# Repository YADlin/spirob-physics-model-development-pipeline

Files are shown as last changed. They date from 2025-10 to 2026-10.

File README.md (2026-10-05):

# SpiRob generator

Design a cable-driven SpiRob, inspect its geometry, and generate a **MuJoCo model** or **fabrication CAD** from one JSON file. Two cables use flat rectangular/hex links and hinge joints; three or more use notched n-lobe links and ball joints.

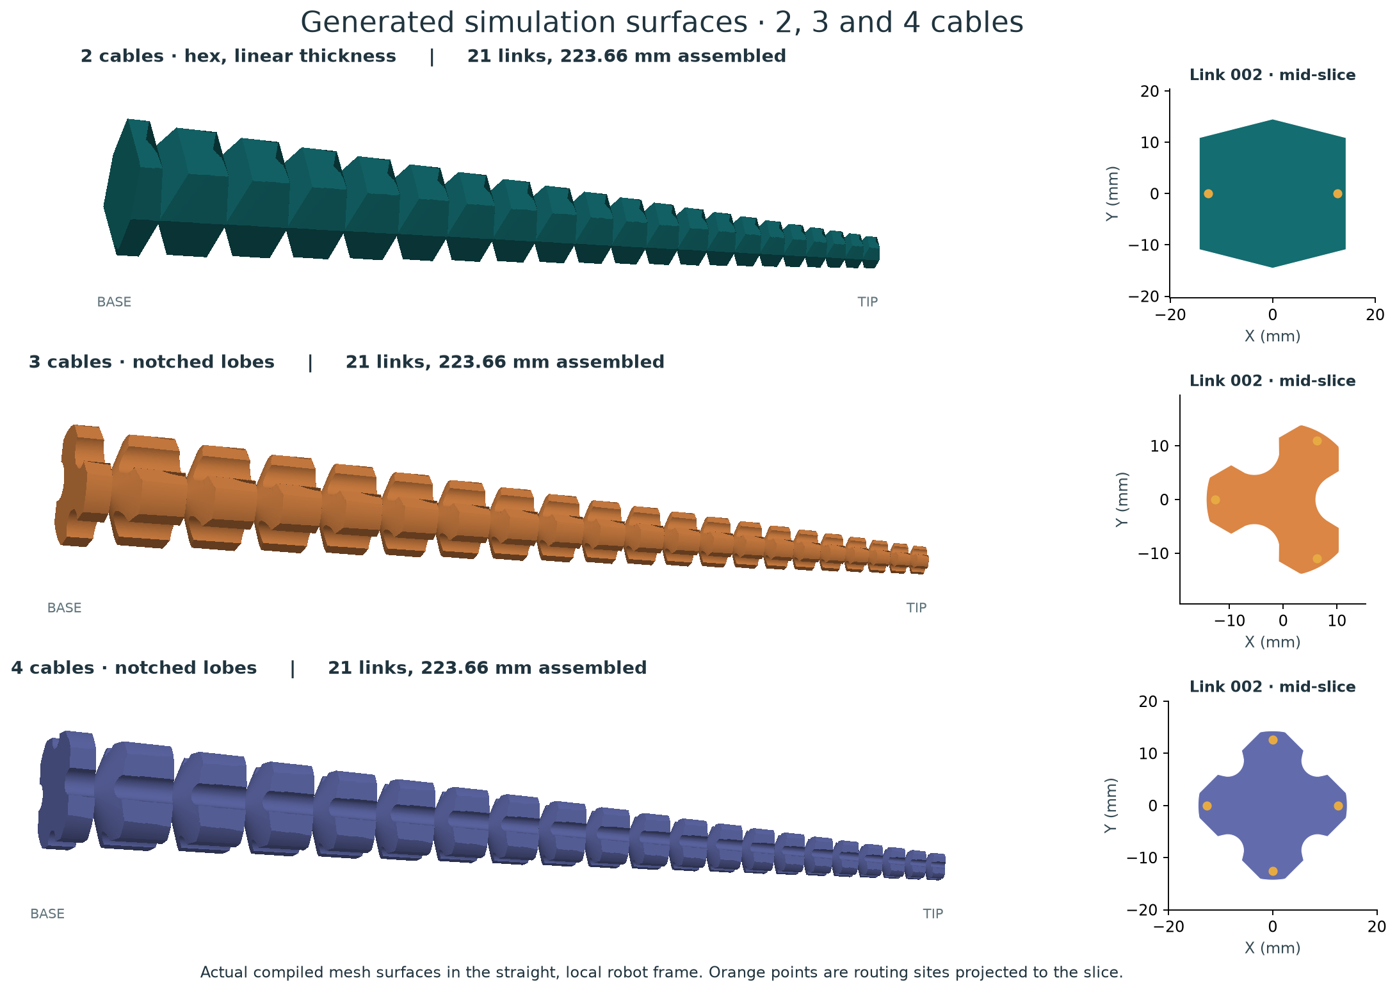
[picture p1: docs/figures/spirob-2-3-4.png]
Actual generated 2-, 3- and 4-cable SpiRob surfaces


**Start here:** [Install and build](#install-and-build) · [Interactive designer](#interactive-designer) · [Parameters](#parameters) · [Geometry equations](#geometry-equations) · [Dynamics and contact](#dynamics-and-contact) · [Tools](#tools) · [GitHub hosting](#github-hosting) · [Verification and layout](#verification-and-layout)

## Install and build

The supported environment is **Python 3.12**, managed by [uv](https://docs.astral.sh/uv/getting-started/installation/). Run commands from the repository root. `uv sync` creates `.venv`; activation is optional. Dependencies, including CAD and MuJoCo, are locked in `uv.lock`.

```bash
git clone git@github.com:YADlin/spirob-physics-model-development-pipeline.git
cd spirob-physics-model-development-pipeline
git switch fix/consolidation-cad-workflows
uv sync --locked
uv run python tools/designer.py
```

The review branch is shown above; after it is merged, use `main`. The designer opens at **http://127.0.0.1:8765**. Select a preset, adjust its parameters, then download JSON or generate a model ZIP. Stop the server with Ctrl+C after a build finishes.

For a terminal build and viewer:

```bash
uv run python build.py --params examples/params-three-cable.json --no-preview --output-dir build/three
uv run python -m mujoco.viewer --mjcf build/three/spirob_physics_model.xml
```

For two-cable hex links with an explicit **20 mm base thickness**, STEP, printing STL and IGES:

```bash
uv run python build.py --params examples/params-two-cable-hex.json --base-thickness-mm 20 --cad --iges --no-preview --output-dir build/two
```

Every build compiles its XML before publishing outputs. Failed stages preserve the previous output. Rebuilding without CAD removes stale CAD from that output directory. The obsolete red `target` site is **absent from new XML**; regenerate old models to remove it there too.

| Output under the chosen directory | Purpose / units |
| --- | --- |
| `spirob_physics_model.xml` + `meshes/` | Portable simulation model. Keep these together; simulation STL coordinates are **metres**. |
| `build_params.json` | Input with resolved build/CLI overrides. Omitted dynamics values still use the documented preset. |
| `Geom_Data_CSV/` | Intermediate geometry table; useful for auditing, not required by the viewer. |
| `collision_summary.json` | Contact geometry counts, mass isolation and arena allocation. |
| `section_dimensions.json` | Two-cable base/tip thickness and per-link taper dimensions. |
| `elastic_core_dimensions.json` | Core percentage, reference-width law and core dimensions at every joint and the tip. |
| `cad/spirob.step`, `cad/spirob.stl` | Whole-robot manufacturing exports in **millimetres**, when CAD is enabled. |
| `cad/spirob.iges` | Optional **trimmed BRep** interchange in mm; STEP is preferred for solids. |
| `cad/spirob_cad_report.json` | CAD validity, volumes, bounds, hashes and round-trip results. |
| `spirob_aligned.mjb` | Optional compiled frame-alignment experiment tied to MuJoCo 3.3.5. |

A fabrication STL and a simulation STL have different units and purposes. Do not send a metre-scale simulation mesh straight to a slicer expecting millimetres.

## Interactive designer

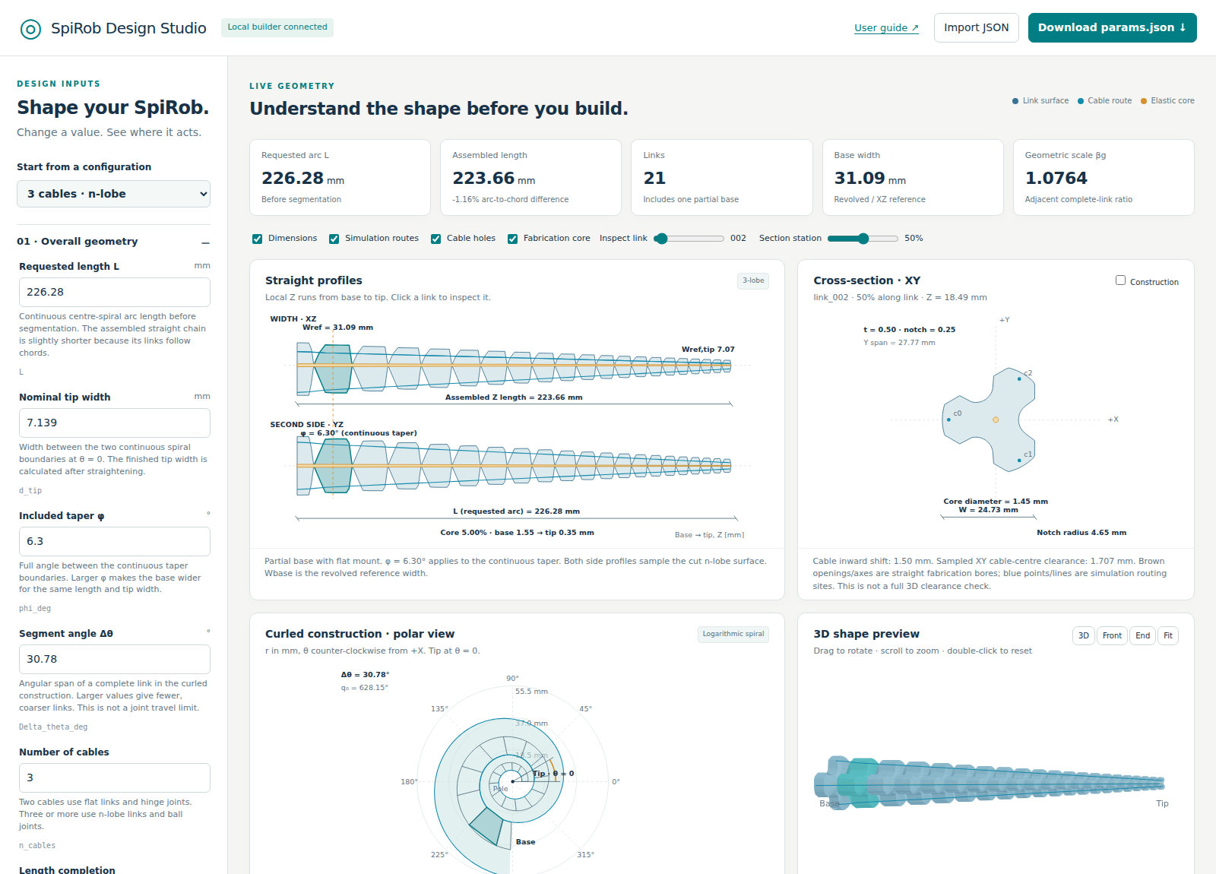
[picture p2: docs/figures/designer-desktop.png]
The SpiRob browser designer


The same interface runs locally or as a static GitHub Pages site. No JavaScript framework, CDN or web account is required to explore a design.

1. Choose a **2-hex, 2-rectangular, 3-, 4- or 6-cable preset**. Other cable counts can be entered.
2. Change length, tip width, taper and segment angle. The **front/side profiles** distinguish requested length from assembled length.
3. Click a link or use **Inspect link**. Move **Section station** to see a real XY slice, rather than a misleading full-link projection. Toggle **Construction** for the polygon and notch cutters.
4. Expand **Section** or **Fabrication** to change thickness, notch, fill, core and hole dimensions. The cross-section reports sampled XY wall clearance. Toggle dimensions, routes and core separately to control clutter.
5. Inspect the polar construction, back-calculated constants, gain plots and rotatable 3D surface. **Front**, **End** and **Fit** provide predictable camera views.
6. Download `params.json`. With the local builder connected, **Generate & download model** runs the Python pipeline and returns the XML, meshes, optional CAD and reports in one ZIP.

The browser remembers the last valid design locally. Importing a JSON file restores its settings; invalid values disable export/build and leave the previous valid preview visible with an error. Length inputs display **mm** while JSON uses metres. Optional omitted settings are identified in the controls.

The 3D view is a sampled design preview, not a contact simulation. Fabrication core/channel overlays explain parameters; the generated CAD is authoritative for the fused/drilled solid. Root world pose is applied in MuJoCo, not in the local design views. Interactive previews and browser builds are bounded to **32 cables / 400 links**; the terminal generator has no 32-cable limit.

**GitHub Pages is static hosting:** it serves the previews and JSON export but cannot execute this Python/OpenCascade pipeline. Exact exports work through the local builder or the manual GitHub Actions workflow described below. See [GitHub Pages documentation](https://docs.github.com/en/pages/getting-started-with-github-pages/what-is-github-pages).

## Parameters

Start with an example and edit it, or use the designer. The schema in [`site/parameters.schema.json`](site/parameters.schema.json) supplies field descriptions, units and basic validation to both Python and the website. Unknown keys, invalid types and non-finite numbers are rejected.

**Precedence:** explicit CLI option → JSON → generator/preset default. Schema `default` entries describe initial designer values; they do not silently insert missing keys into an imported file. The tables distinguish example values from omitted-key behavior where it matters.

### Geometry and sections

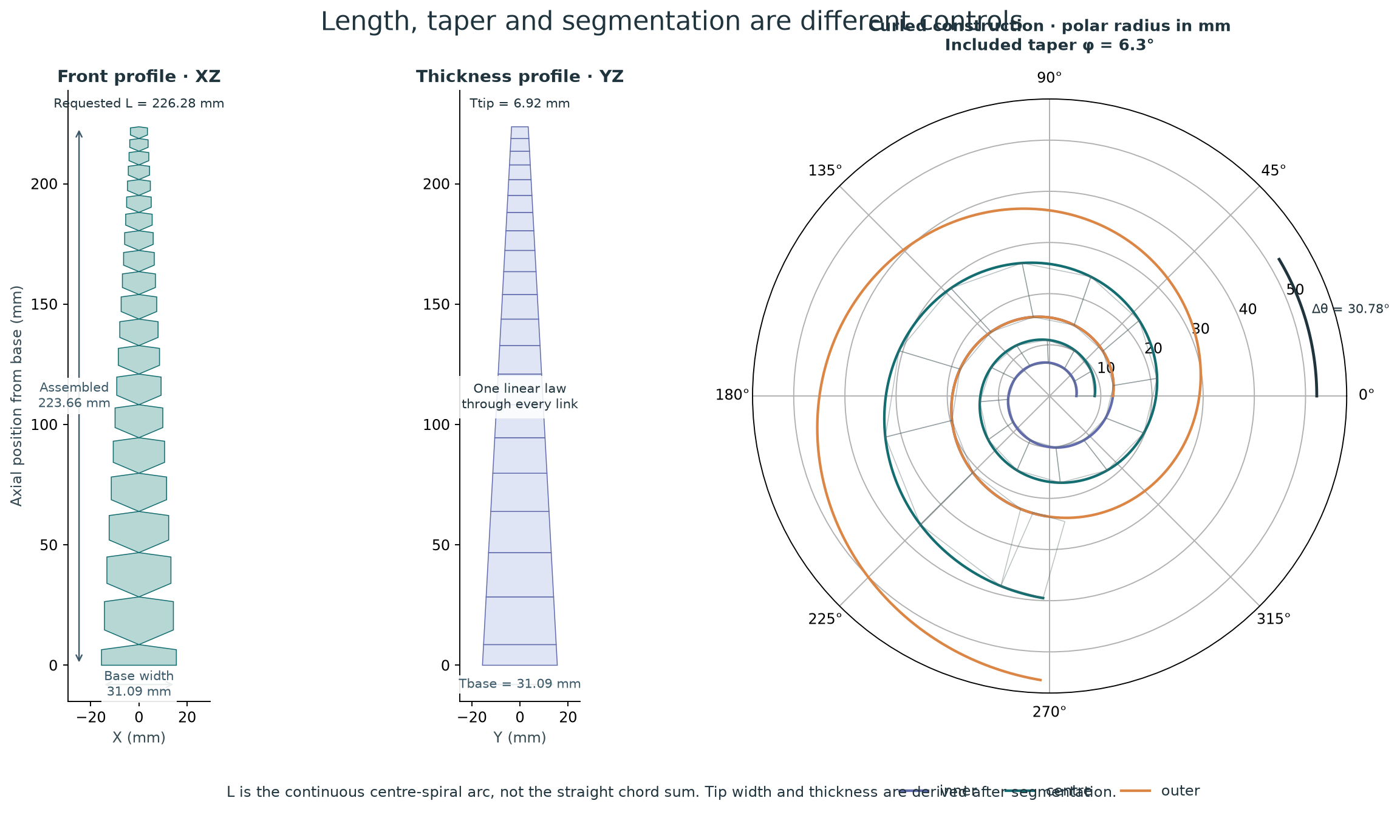
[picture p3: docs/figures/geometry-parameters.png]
Annotated geometry, thickness and spiral parameters


| JSON key | Example / default | Meaning and effect |
| --- | --- | --- |
| `L` | `0.22628` m; required | Continuous centre-spiral arc length before straightening. The assembled chain follows chords and is slightly shorter. |
| `d_tip` | `0.007139` m; required | Nominal width between spiral boundaries at θ=0. It is not necessarily the final measured tip width after segmentation. |
| `phi_deg` | `6.3`; required | Full included taper angle φ, **0 < φ < 45°**. Increasing it widens the base at a fixed length/tip input. |
| `Delta_theta_deg` | `30.78`; required | Curled angular span per complete link, **0 < Δθ < 180°**. Larger values mean fewer links; it is not a joint limit. |
| `n_cables` | `3`; required | Integer ≥2. Selects flat hinge links for 2, n-lobe ball-joint links for n≥3. |
| `terminal_unit_policy` | `exact_requested_length` | Preserve requested arc length and allow a partial base; `whole_units` extends the arc to the next complete link. An excessively short partial base is rejected; use whole units or adjust L/Δθ. |
| `tendon_inward_shift` | `0.0015` m; required | Inward routing-site offset; **0 ≤ shift < d_tip/2**. The distal site also receives a taper correction. This is not a guaranteed distance from a drilled hole to the actual outer surface. |
| `base_thickness_m` | `null` / auto | **2-cable only.** Full Y centre thickness at the base mounting plane. Auto equals base width; a number fixes that base thickness. Tip thickness is derived, not independently entered. |
| `thickness_profile` | `linear` | **2-cable only.** One continuous thickness law within and between links. `stepped` is the legacy constant-thickness-per-link alternative. |
| `flat_section` | `rectangular` | **2-cable only.** `hex` adds two centre ridges, giving a six-sided section; it is generally not a regular hexagon. |
| `hex_edge_ratio` | `0.75` | Hex only; **0 < ratio < 1**. Edge/centre thickness ratio at the link's full-width section. Sloped end-face clipping also changes a slice near a joint. |
| `nlobe_t` | `0.5` | **n≥3.** Polygon fill, **0–1**. Sets polygon circumradius relative to the revolved reference radius; changing it changes the lobe outline. |
| `notch_factor` | `0.25` | **n≥3.** Notch radius / half polygon-side length, **0–0.4**. Zero means no notch. Convex contact bridges these concavities. |
| `show_preview` | `false`; required | Open the optional desktop 2D approval window during a CLI build. `--no-preview` and the local browser builder suppress it. |

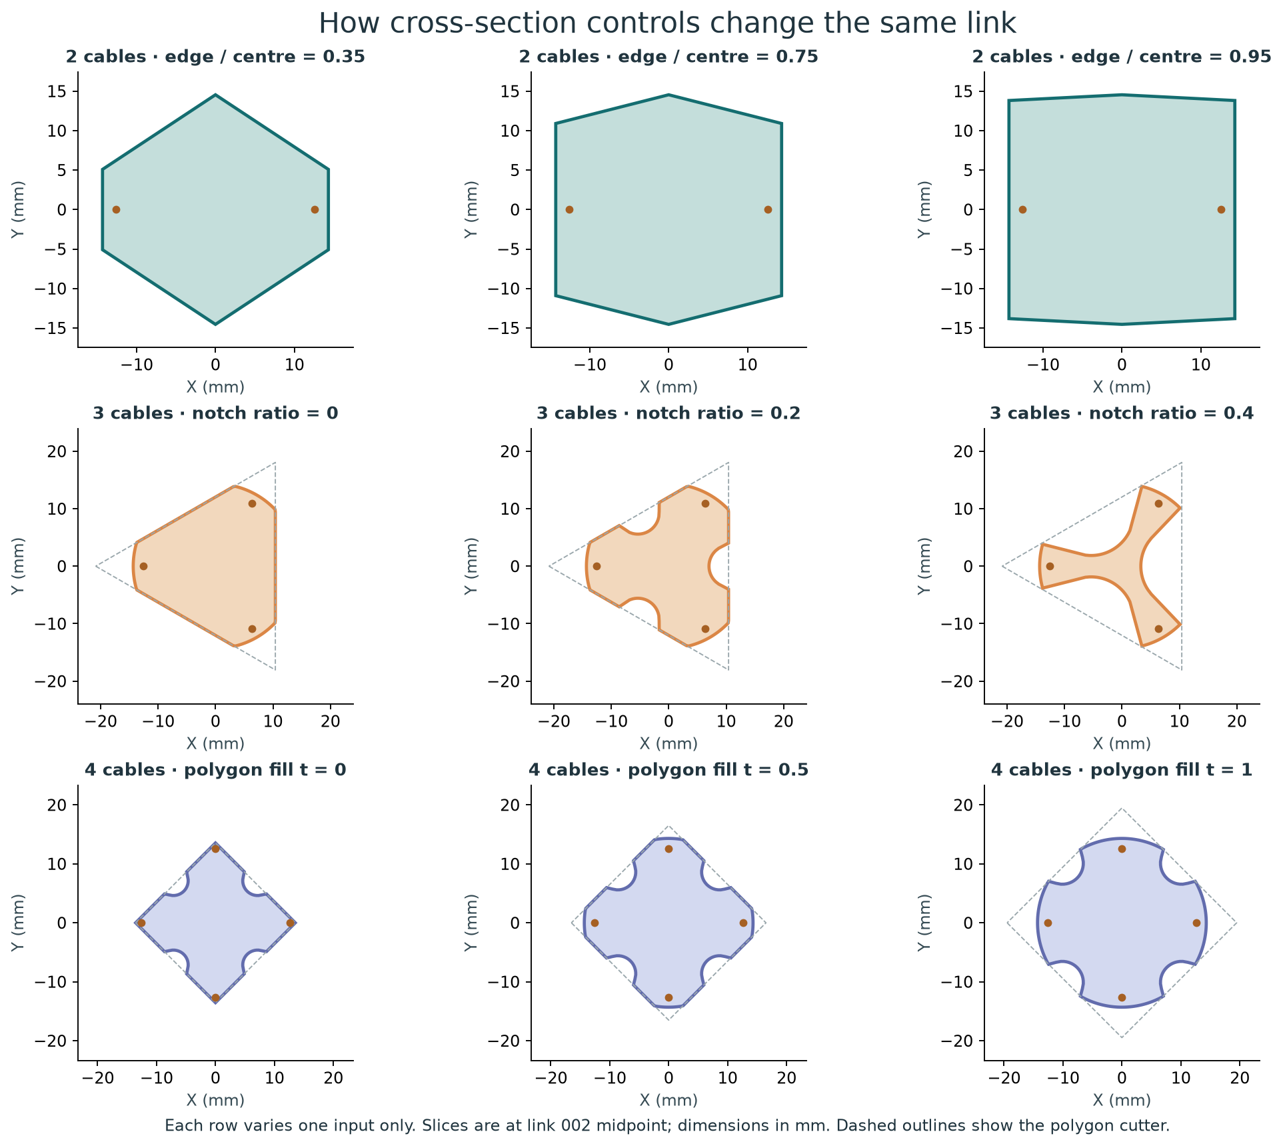
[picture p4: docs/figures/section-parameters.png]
Effects of hex edge ratio, notch ratio and polygon fill


For two cables the thickness law is

$$T(z)=T_\mathrm{base}\frac{z_\mathrm{apex}-z}{z_\mathrm{apex}-z_\mathrm{base}}.$$

The virtual apex continues the geometric sequence beyond the tip. This gives a linear taper and preserves similarity of complete links, so they can share an STL. The partial base gets its own STL. See `section_dimensions.json` for the resulting **base and tip** dimensions.

### Placement and dynamics: `post_gen`

These keys belong inside a `"post_gen": {...}` object. They are optional; examples explicitly set them for reproducibility.

| Key | Example | Meaning / omitted-key behavior |
| --- | --- | --- |
| `robot_pos` | `[0,0,0.22628]` m | Root body world position. If omitted, use the generated root position. |
| `robot_quat` | `[0,0,-1,0]` | Root orientation `[w,x,y,z]`, nonzero. The example points local +Z down. If omitted, use the generated orientation. |
| `joint_stiffness_base` | `0.2` N·m/rad | K₀ coefficient of the gain law below. Omitted uses the chosen preset. |
| `joint_damping_base` | `0.01` N·m·s/rad | D₀ coefficient; omitted uses the preset. |
| `joint_beta` | `1.03` | Positive gain-decay βⱼ, independent of geometric βg. Above 1 gives decreasing gains; 1 gives constant gains. |
| `first_joint_stiffness` | `100` N·m/rad | Override j_001 only. If omitted, j_001 follows K₀. A large spring approximates a fixed mounting; it is not a weld. |
| `first_joint_damping` | `50` N·m·s/rad | Override j_001 only. If omitted, it follows D₀. |
| `timestep` | `0.0001` s | Positive integration step. All supplied examples set this explicitly. Omitted uses the preset, which can be much coarser. |
| `tip_site_pos` | `[0,0,0.005]` m | Optional `tip_site` location in the **last body's local frame**; not a world position or guaranteed physical tip. Omitted means no tip site. |

`post_gen.target_site_pos` is retired: imports remove it with a notice and no target is emitted. The `--show-target-marker` flag has been removed.

### Export, collision and fabrication: `build`

These keys belong inside a `"build": {...}` object. The two example build entries are `collision_mode: "convex"` and `mesh_layout: "shared"`; other entries can be added in JSON or selected in the designer.

| Key | Default / example | Meaning |
| --- | --- | --- |
| `collision_mode` | Examples: `convex` | One massless convex hull per link. Alternatives: `mesh`, `capsule`, `compound`; comparison below. Omitted: mesh, or capsule with safe preset. |
| `mesh_layout` | `shared` | Reuse a complete-link STL plus a partial-base STL where needed. `individual` creates one mesh file per link. Names inside XML remain stable. |
| `physics_preset` | `default` | `default`, `safe`, `fast`, `high`. Selects the legacy dynamics/contact defaults; explicit overrides still win. |
| `collision_margin_m` | `null` / auto | Nonnegative activation margin in metres. Auto is **0 for convex/compound**, otherwise the preset value. |
| `collision_corner_radius_ratio` | `0.04` | Corner radius / half-width for legacy compound colliders only. Does not affect convex. |
| `arena_memory_mib` | `null` / auto | Positive integer native MuJoCo arena size. Auto is 128 MiB for compound, compiler default otherwise. More memory does not fix unstable dynamics. |
| `plain` | `false` | Advanced revolved circular-section comparison; bypasses flat/n-lobe cutters. Incompatible with convex/compound and explicit flat-section settings. |
| `align_geom_frames` | `false` | Additional version-specific aligned `.mjb`. Ordinary XML still uses MuJoCo's mesh principal frames. Usually leave off. |
| `cad` | `false` | Enable whole-robot STEP and mm STL export plus validation report. |
| `cad_profile` | `fabrication` | `fabrication` fuses a central elastic core and optional channels. `simulation` assembles the rigid link surfaces; it is not necessarily one printable part. |
| `elastic_core_percent` | `5` (%) | Core **X width for 2 cables**, **diameter for n≥3**, as a percentage of the local continuous reference width. Strictly between 0 and 100; `5` means 5%. Narrows continuously from base to tip. |
| `cable_hole_diameter_mm` | `0` mm | Fabrication channel diameter; 0 leaves CAD undrilled. Positive diameters require fabrication profile. Does not change tendon display width or simulation mass. |
| `fuse_cad` | `false` | Fuse simulation-profile solids where possible. Fabrication is already fused. Requires CAD. |
| `iges` | `false` | Also export trimmed IGES BRep, in mm. Requires CAD; STEP remains the preferred solid exchange format. |

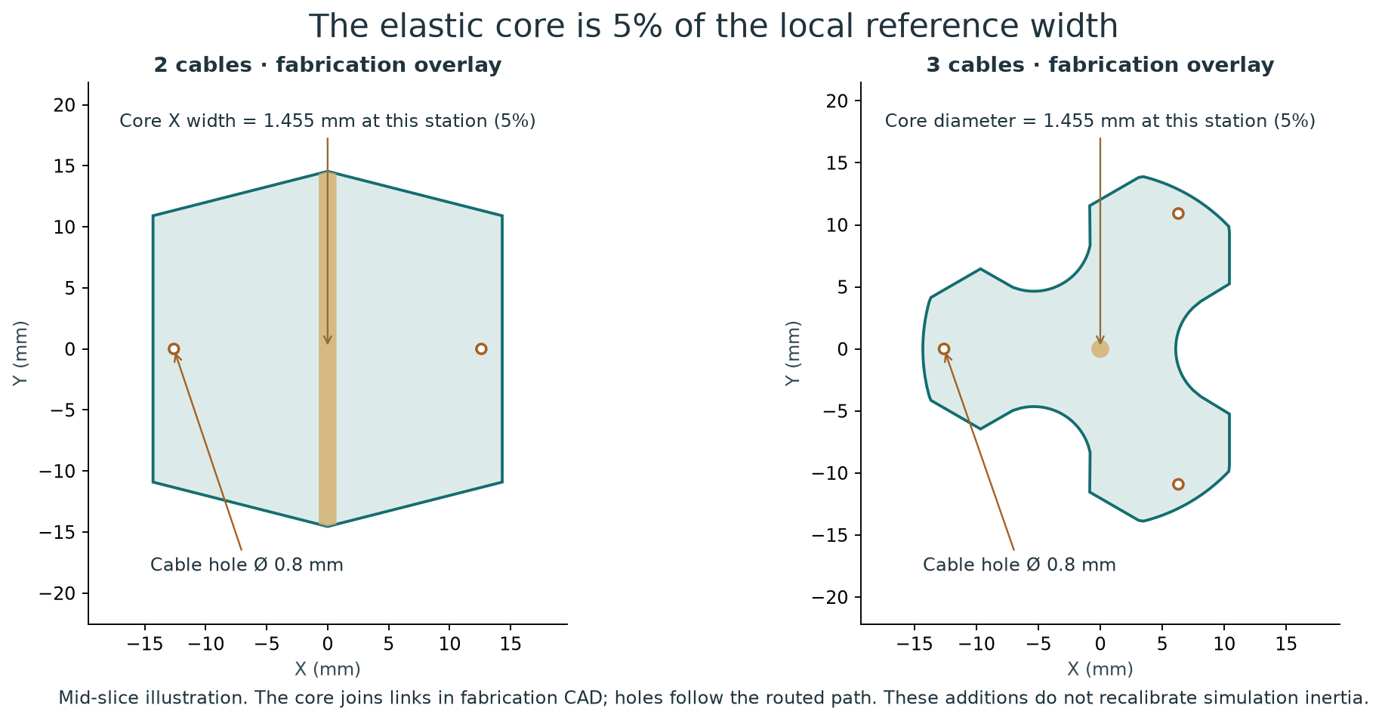
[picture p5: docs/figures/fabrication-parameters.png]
Core and cable-hole dimensions for two- and three-cable SpiRobs


**The elastic core must taper.** At axial position $z$, its X width (two cables) or diameter (n cables) is

$$c(z)=\frac{p}{100}W_{\mathrm{ref}}(z),\qquad
W_{\mathrm{ref}}(z)=W_{\mathrm{base}}\frac{z_* - z}{z_* - z_{\mathrm{base}}}.$$

Here $p$ is `elastic_core_percent`, and $z_*$ is the virtual apex beyond the tip. The reference width is the **continuous straightened, pre-notch envelope**, anchored to the base mounting width and the existing geometric similarity law. It is not the zero material width at a slit, the n-lobe notch clearance, or the XY bounding width of a clipped slice. All three fabrication formats use the same fused tapered solid.

For the supplied standard geometry at 5%, the reference width decreases from **31.087574 mm to 6.923663 mm**, and the core width/diameter decreases from **1.554379 mm to 0.346183 mm**. Two-cable core Y thickness follows the chosen link-thickness profile; with the default linear profile both transverse dimensions decrease. Its hex ridge edges follow the existing ridge geometry. For n cables the core is a circular conical frustum. An explicitly selected legacy stepped/lens Y profile retains that Y behavior; the new core X width still tapers continuously.

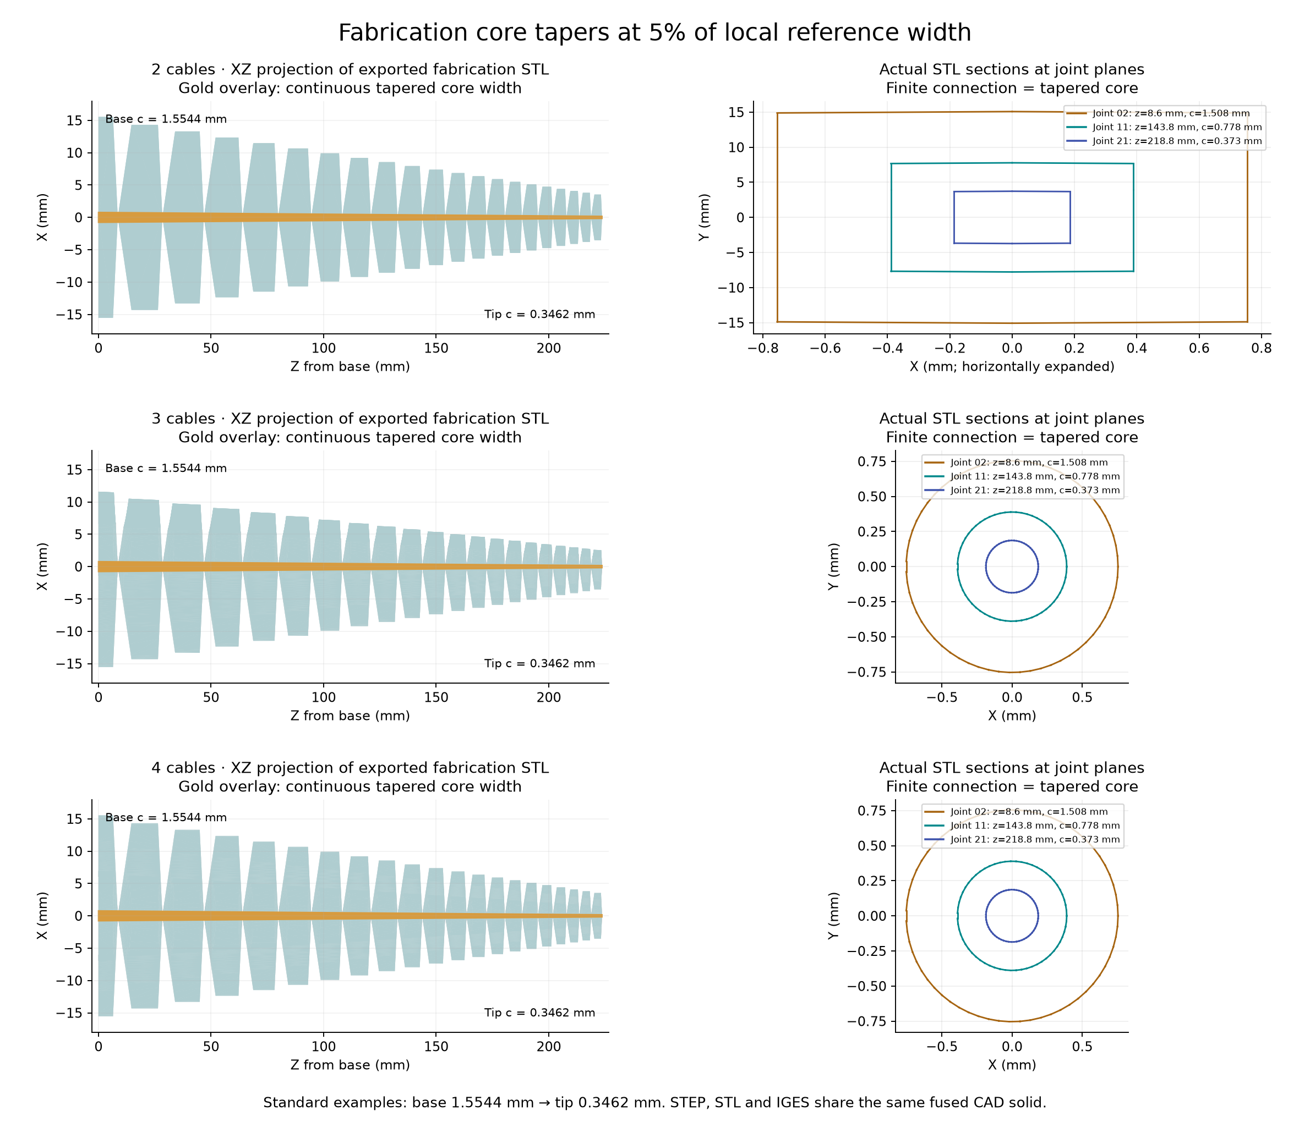
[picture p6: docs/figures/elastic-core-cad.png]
Tapered fabrication cores and their measured joint sections


```bash
uv run python build.py --params examples/params-two-cable-hex.json --elastic-core-percent 5 --cad --iges --no-preview --output-dir build/tapered-core-two
uv run python build.py --params examples/params-three-cable.json --elastic-core-percent 5 --cad --iges --no-preview --output-dir build/tapered-core-three
```

In JSON, set `"elastic_core_percent": 5` inside `build`. In the designer, expand **Elastic core & channels** and change **Elastic core / local width**. The core overlay, section dimensions and 3D core update together. Move the selected link and section station to see the narrowing. `elastic_core_dimensions.json` records joint-station values; the CAD report repeats the law used to construct the solid.

**Old inputs:** `build.neck_width_mm` and `--neck-width-mm` are migration inputs specifying the **base** core dimension. They now convert to a percentage, preserving that base size while reducing the tip. A notice identifies the behavior change. Do not supply both the legacy size and the percentage. There is no constant-width core mode in new fabrication exports.

**Original-author convention:** the inspected upstream DesignTool (`f563e69`) scales the half-taper angle by its “Elastic %”. Its corresponding width ratio is $\tan((p/100)\phi/2)/\tan(\phi/2)$, approximately $p/100$ for small angles. Our control explicitly specifies the width percentage requested here; the two numbers should not be treated as exactly identical. See [upstream DesignTool](https://github.com/ZhanchiWang/Open-Spiral-Robots/blob/f563e69f292a6b8cac1946dc45ad9e60d8795391/design-tool/DesignTool.py). The construction here is independent; no upstream implementation is copied.

The core controls geometry, not a separately identified material layer. Changing its percentage does **not** automatically calibrate joint gains or add the fabrication core/hole mass to the simulation inertias.

Cable-hole margin depends on the selected link, slice, notch shape, taper and hole diameter. The browser's XY clearance estimate is useful for locating thin walls, but is not a 3D minimum-wall or print-strength certification. Check the exported solid before printing.

### Compatibility inputs and command-line help

| Retained input | Purpose |
| --- | --- |
| `flat_thickness_ratio` | Old two-cable base thickness/width ratio, 0.05–1; mutually exclusive with `base_thickness_m`. Prefer absolute base thickness. |
| `flat_edge_ratio` | Old fabrication lens edge ratio, (0,1]; not the current hex-section control. |
| `taper_angle_deg` | Legacy alias; must agree with `phi_deg`. Use `phi_deg` in new files. |
| `build.flat_thickness_m`, `build.flat_edge_ratio` | Legacy stepped fabrication-lens overrides. Not supported with hex/linear thickness. |
| `_comment` | Optional explanatory string at root, in `post_gen`, or in `build`. |

Every terminal flag has help text:

```bash
uv run python build.py --help
uv run python tools/set_joint_gains.py --help
uv run python tools/add_touch_sensors.py --help
```

CLI names use hyphens: e.g. `--collision-mode convex`, `--arena-memory-mib 128`, `--elastic-core-percent 5`. `--base-thickness-mm 20` converts mm to the JSON metre value; `--base-thickness-mm auto` restores thickness=width. `--hex-section` selects hex, `--safe/--fast/--high` select a preset, and `--nlobe` restores the cable-count-driven section after `build.plain`. `--no-cad`, `--no-iges`, `--no-fuse-cad`, and `--no-align-geom-frames` can disable JSON options. `--noclean` is a retained no-op: builds always use fresh staging.

## Geometry equations

The original design principle is the logarithmic spiral **r(θ)=a exp(bθ)**, described by Wang, Freris and Wei in [SpiRobs: Logarithmic Spiral-shaped Robots for Versatile Grasping Across Scales](https://arxiv.org/abs/2303.09861). This generator solves for constants from more direct design inputs; the website displays their current values.

Let $E=e^{2\pi b}$. In this repository's convention:

$$r_\mathrm{in}(\theta)=ae^{b\theta},\quad r_\mathrm{out}(\theta)=ae^{b(\theta+2\pi)},\quad r_c(\theta)=\frac{a(E+1)}{2}e^{b\theta}.$$

$$\tan(\phi/2)=\frac{b(E-1)}{\sqrt{1+b^2}(E+1)},\qquad a=\frac{d_\mathrm{tip}}{E-1}.$$

$$A=\frac{\sqrt{1+b^2}\,a(E+1)}{2b},\qquad L=A(e^{bq_0}-1),\qquad q_0=\frac{\ln(1+L/A)}{b}.$$

Angles in these equations are **radians**. Complete units span Δθ and have geometric size ratio $\beta_g=e^{b\Delta\theta}$. The generator straightens each centre chord, reverses tip-to-base construction into base-to-tip numbering, and corrects a partial base's mounting face. Hence requested continuous length, discrete length and measured end widths differ. Whole-unit policy rounds the angular span upward before assembly.

For n-lobe links, the cutter has polygon circumradius $R_p=R[1+t(\sec(\pi/n)-1)]$ and notch radius $r_n=\text{notch\_factor}\,R_p\sin(\pi/n)$. The actual slice also includes axial draft and the revolved slit envelope; the website applies both.

## Dynamics and contact

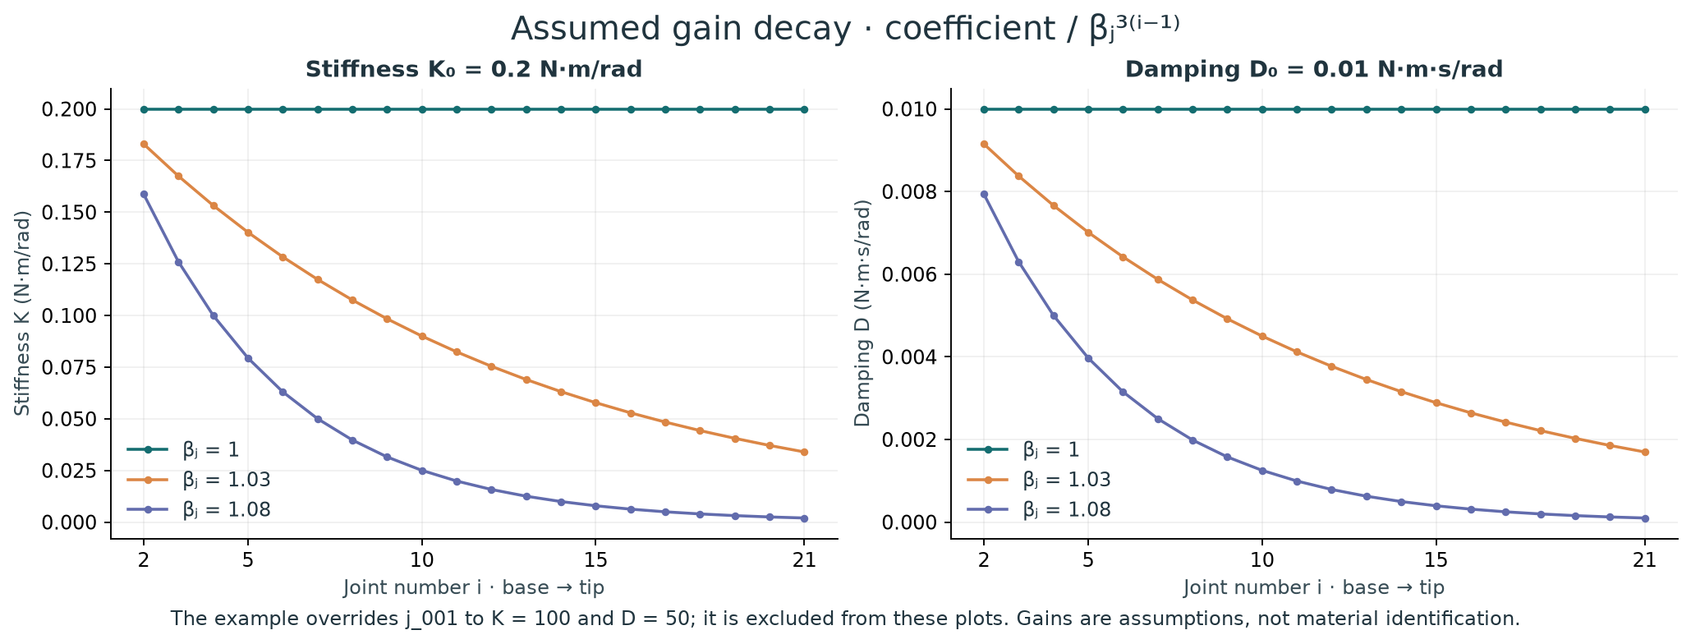
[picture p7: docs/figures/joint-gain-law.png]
Stiffness and damping curves for several decay assumptions


For base-to-tip joint number $i=1,\ldots,N$:

$$K_i=K_0/\beta_j^{3(i-1)},\qquad D_i=D_0/\beta_j^{3(i-1)}.$$

This is an **assumed exponential law in joint index** with the same exponent for damping and stiffness. It is retained and tested in this update. It is not fitted automatically to the printed material or inferred from CAD. βⱼ is independent of geometric βg. There is no linear joint-gain mode; the linear option described earlier refers to **link thickness**. The example's j_001 overrides are applied after this law. For ball joints, damping applies to their three rotational degrees of freedom.

### Why a linear core taper can coexist with exponential joint gains

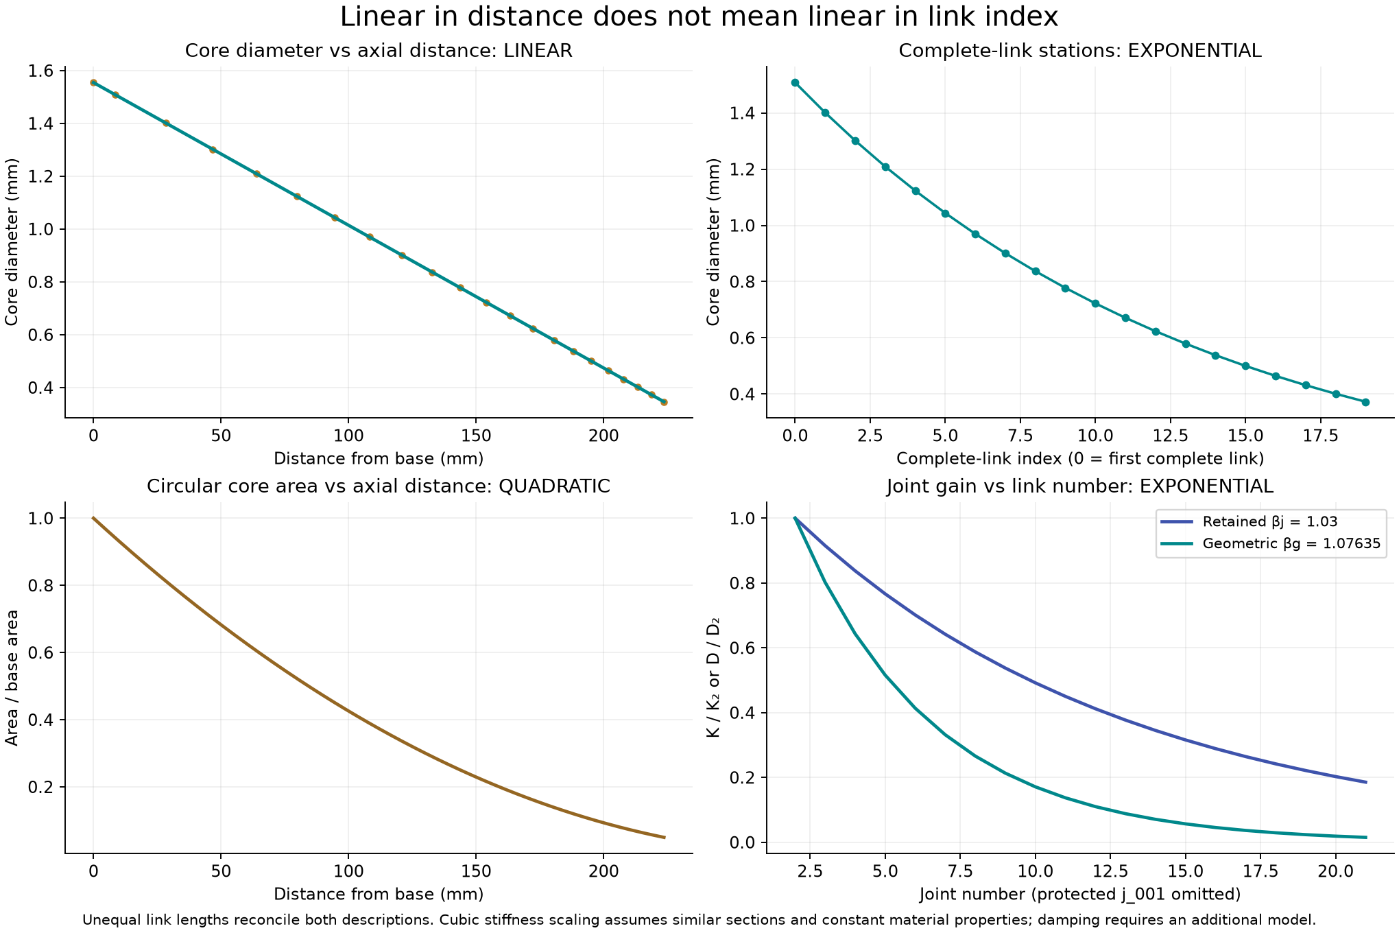
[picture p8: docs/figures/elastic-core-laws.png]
Width versus distance, width versus link index, and joint gain decay


Complete links occupy equal increments of spiral angle, **not equal axial distances**. Their sizes form a geometric sequence with tipward factor $s=1/\beta_g=e^{-b\Delta\theta}$. Sampling a linearly tapered width at these unequally spaced positions therefore gives an exponential sequence in link number. The partial base is handled by its actual length in the core geometry; it need not have the complete-link size ratio.

| Quantity / coordinate | Reduction toward the tip |
| --- | --- |
| Core width/diameter versus straight axial position $z$ | **Linear**, to a virtual apex beyond the actual tip. |
| Core width/diameter at corresponding complete-link stations | **Geometric / exponential**: one factor $1/\beta_g$ per link. |
| Nominal similar core cross-sectional area versus $z$ | **Quadratic** when both transverse dimensions scale; legacy fixed-Y variants differ. Hex CAD ridge clipping can introduce small departures from perfect section similarity. |
| Implemented stiffness and damping versus joint index | **Exponential**: one factor $1/\beta_j^3$ per joint, except explicit base overrides. |

For geometrically similar elastic sections of the same material, rotational bending stiffness scales approximately as $K\sim EI/\ell$. When all dimensions scale by $s$, $I\sim s^4$ and $\ell\sim s$, hence $K\sim s^3$. A linear Kelvin–Voigt bending model with a constant material viscosity gives the same cubic scale for damping; real TPU damping must be measured. This is the physical motivation for the exponent **3**, not proof that the current coefficients reproduce the printed robot.

`joint_beta` remains independent so existing calibrated/tuned configurations are preserved. To impose the complete-link similarity assumption, use the displayed **geometric βg** as `post_gen.joint_beta`. In the standard example βg ≈ **1.076353346**, while the retained example gain βj is **1.03**. They produce different gain reductions. With βj=βg, the ideal corresponding-station gain law is cubic in distance to the virtual apex; an arbitrary βj gives a different power of that distance. The current joint-index law is not corrected for a partial first link, and j_001 retains its independent mounting override. There is no claim of automatic physical calibration.

Legacy presets are retained, with their limitations visible:

| Preset | Timestep if omitted | Integrator | K₀ / D₀ if omitted | Motor control range | Margin for mesh/capsule |
| --- | --- | --- | --- | --- | --- |
| default | 0.002 s | implicit | 0.2 / 0.01 | −10 to 0 | 0.001 m |
| safe | 0.001 s | implicit | 0.2 / 0.2 | −5 to 5 | 0.0002 m |
| fast | 0.005 s | implicit | 0.01 / 0.001 | −10 to 10 | 0.002 m |
| high | 0.0005 s | RK4 | 0.1 / 0.02 | −5 to 5 | 0.0005 m |

**All current examples explicitly use 0.0001 s.** Their explicit K₀/D₀ also override preset gains. Preset names are not stability or physical-accuracy guarantees. Keep your known tolerable timestep and test the intended force/load range. With the default motor convention, negative control tensions the tendon; the symmetric legacy ranges also permit the opposite sign. Cable motors are idealized, not a hardware motor/cable model.

| Contact mode | Use / approximation |
| --- | --- |
| `convex` | Recommended starting point in examples: one massless contact hull per link, independent visual mesh and explicit inertia. Supports flat and n-lobe links. Bridges n-lobe concave notches. Multiple contact points can still be necessary for a broad face. |
| `mesh` | MuJoCo mesh contact uses a convex hull; it does not reproduce arbitrary concavity. Retains older contact settings. |
| `capsule` | Cheap rounded approximation, which can differ noticeably from flat faces. |
| `compound` | Legacy boxes/cylinders for **stepped rectangular two-cable links only**. More geom pairs and contacts; retained for comparisons. |

One hull per link reduces the number of contact geoms; it does **not** guarantee one contact or constraint per link. Dense folded configurations can still produce many contacts. Inspect force aggregation and solver statistics before increasing memory. Viewer `100% (76.2%)` describes requested versus achieved real-time speed; it is not an accuracy score.

Mass, COM and inertia are frozen into explicit `<inertial>` elements from the **simulation visual meshes** at generation time, using uniform density **1200 kg/m³**. Collision proxies have zero mass. Fabrication ligaments, holes, print infill and material variation are not automatically incorporated into this model. Geometry/density changes require regeneration; measured hardware properties require separate calibration. `audit_inertia.py` compares the assumptions transparently.

MuJoCo can rotate mesh geom frames to principal axes during compilation. This does not by itself rotate the physical surface incorrectly. Body/site naming is retained: `link_NNN`, `j_NNN`, `cC_NNN_s1/s2`, `cable_C`, `motor_cC`, and optional `tip_site`. See [MuJoCo's mesh documentation](https://mujoco.readthedocs.io/en/3.3.5/XMLreference.html#asset-mesh).

## Tools

All tools are included in the repository. Run them from the repository root. XML editing tools write a **separate compiled output** and rebase asset paths; keep the original meshes available. Use `--help` for complete options.

| Tool | When it helps |
| --- | --- |
| `tools/designer.py` | Interactive design and exact local model/CAD ZIP generation. `design_gui.py` is a compatibility launcher for this interface. |
| `tools/set_joint_gains.py` | Tune one stiffness/damping coefficient and decay factor across joints; always preserves j_001 and optional extra exclusions. |
| `tools/add_touch_sensors.py` | Add named spherical touch regions near cable routes while preserving existing sensors and physical properties. |
| `tools/audit_inertia.py` | Compare compiled mass/COM/inertia against the triangle mesh, independent simulation CAD, and optionally an older XML. |
| `tools/inspect_collision.py` | Show CAD and contact proxies, report counts/mass separation, or run a bounded actuator/contact stress test. |
| `tools/inspect_collision_surface.py` | Plot and quantify the visual-surface versus collision-hull difference, especially bridged n-lobe notches. |
| `tools/inspect_contact_forces.py` | Sum world-frame contact forces and moments on a body or within a chosen body-local spherical region. |
| `tools/inspect_section.py` | Plot actual compiled mesh projections and 3D views in body coordinates. Its end-on projection is not a planar slice. |
| `tools/inspect_taper.py` | Check two-cable thickness continuity against the requested law; optionally compare an older XML. |
| `tools/multi_array.py` | Assemble a circular array of robots with namespaced names and shared assets. |
| `fabrication/part_splitter.py` | Split STEP/STL to an axial printer span or explicit cuts; records part bounds and volumes. It does not add assembly keys or restore flexure continuity. |
| `tools/preview.py` | Optional desktop 2D geometry approval window used by `show_preview`. |
| `tools/inspect_model.py` | Advanced body/geom-frame inspection and optional compiled alignment. |
| `tools/geometry_audit.py` | Advanced requested/discrete length and geometry-policy report. |
| `tools/benchmark_collision.py` | Developer comparison of collider contact counts, timings and dense poses. Not a hardware validation. |

### Change gains and preserve the base

```bash
uv run python tools/set_joint_gains.py --mjcf build/three/spirob_physics_model.xml --out build/three/tuned.xml --stiffness 0.15 --damping 0.008 --beta 1.03 --json build/three/gain_changes.json
uv run python -m mujoco.viewer --mjcf build/three/tuned.xml
```

By default, the coefficient is anchored at the generator's i=1, while j_001 is preserved. Therefore j_002 gets coefficient/β³. Add `--anchor first-flexible` if the entered value should be the actual value at j_002. The tool verifies unchanged inertia, geometry, sites and actuator settings. For a permanent rebuild setting, also edit the corresponding `post_gen` values in your source JSON.

### Compare inertia in a useful frame

```bash
uv run python tools/audit_inertia.py --mjcf build/three/spirob_physics_model.xml --params build/three/build_params.json --links link_001 link_002 link_021 --json build/three/inertia.json
```

Reports express the tensor **at the compiled COM, with axes parallel to the link body frame**. CAD/mesh tensors are shifted to that same point before comparison, and each reference COM is reported separately. MuJoCo's diagonal principal moments alone would not permit a meaningful element-by-element comparison with a differently rotated CAD tensor. The reference is homogeneous CAD, not a measurement of a printed part. Adjust link names for a different link count.

### Inspect contact geometry and forces

```bash
uv run python tools/inspect_collision.py --mjcf build/three/spirob_physics_model.xml --view
uv run python tools/inspect_collision.py --mjcf build/three/spirob_physics_model.xml --stress --controls -2 0 0 --seconds 2 --ramp-seconds 1 --json build/three/contact_stress.json
uv run python tools/inspect_collision_surface.py --mjcf build/three/spirob_physics_model.xml --out build/three/contact_surfaces.png --json build/three/contact_surfaces.json
uv run python tools/inspect_contact_forces.py --mjcf build/three/spirob_physics_model.xml --body link_002 --seconds 2 --controls -2 0 0 --ramp-seconds 1 --json build/three/forces.json
```

For a region rather than the whole link, add `--point-local-m X Y Z --radius-m R`. A finite region aggregates nearby contacts; a mathematical point does not define a unique contact-force distribution. Reports state which body receives the force and the moment reference. No-contact states naturally return zero.

### Add touch readings

```bash
uv run python tools/add_touch_sensors.py --mjcf build/three/spirob_physics_model.xml --out build/three/touch.xml --links 2 3 --offset-mm 1.8 --radius-mm 3
```

This adds regions named `cs_NNN_cC` and sensors named `touch_NNN_cC`. MuJoCo touch readings sum **normal contact-force magnitudes** within a region; they are not independent 3D force vectors. Overlapping regions may count the same contact. Use the contact-force inspector for vector forces and moments. See [MuJoCo touch sensor semantics](https://mujoco.readthedocs.io/en/3.3.5/XMLreference.html#sensor-touch).

### Check thickness, make an array, or split a print

```bash
uv run python tools/inspect_taper.py --mjcf build/two/spirob_physics_model.xml --params build/two/build_params.json --out build/two/taper.png --json build/two/taper.json
uv run python tools/inspect_section.py --mjcf build/three/spirob_physics_model.xml --out build/three/sections.png
uv run python tools/multi_array.py --in build/three/spirob_physics_model.xml --count 4 --radius-m 0.12 --out build/array.xml
uv run python fabrication/part_splitter.py build/two/cad/spirob.step --axis z --max-span-mm 100 --file-units mm --out-dir build/two/print-parts
```

Fabrication exports use the robot's local +Z axis. Splitting reports geometric pieces, not a tested mechanical connection. Inspect where the core and cable channels intersect each cut.

## GitHub hosting

The site and workflows are included; publication is a separate repository action. You can review everything locally before merging.

**After the workflow files reach the default branch:**

1. In GitHub, open **Settings → Pages → Build and deployment → Source: GitHub Actions**.
2. Open **Actions → Deploy SpiRob designer → Run workflow**. Select the branch/ref you intend to publish.
3. Use the URL reported by the deployment. For this repository, the normal project URL is `https://yadlin.github.io/spirob-physics-model-development-pipeline/`; it becomes available only after a successful deployment.
4. To generate files on GitHub, open **Actions → Generate SpiRob model → Run workflow**. Choose a preset or paste a complete exported JSON. Enable `build.cad` and `build.iges` in that JSON for CAD/IGES. Download `spirob-model` from the completed run's artifacts (retained for 14 days).

The website never asks for a GitHub token. Manual Actions builds require repository write access; public visitors can use JSON export and the local builder. A manual workflow must exist on the default branch before GitHub exposes it, even if a later run selects another branch. See [manual workflow requirements](https://docs.github.com/en/actions/how-tos/manage-workflow-runs/manually-run-a-workflow) and [Pages custom workflows](https://docs.github.com/en/pages/getting-started-with-github-pages/using-custom-workflows-with-github-pages).

## Verification and layout

```bash
uv sync --locked
uv run pytest -q
```

For website development, Node 22+ is needed only for checks, not for serving the site:

```bash
uv run python dev/check_web_geometry.py
uv run python dev/check_web_sections.py
npm --prefix dev/browser ci
cd dev/browser
npx playwright install chromium
cd ../..
node dev/browser/check.mjs
uv run python dev/render_readme_figures.py
```

The browser check exercises real controls, JSON persistence, mobile layout and a downloadable XML/STL/STEP/IGES build. Geometry parity compares 24 browser/Python configurations. README figures are reproducible from generated meshes and the same section equations; they are not hand-drawn approximations of hardware.

**Known test status:** one strict expected failure records the retained distal-tendon taper correction (F08), which does not produce a constant surface offset. It is not an unexplained crash; changing it needs a separate routing/physics decision. Sixteen skips cover unsupported n-cable compound combinations; three skips exclude non-legacy profiles from a deliberately legacy benchmark. These do not skip convex coverage. Unexpected failures or new skips still need investigation. See the [current branch audit](docs/engineering/BRANCH_AUDIT.md) for measured results and remaining work.

| Location | Responsibility |
| --- | --- |
| `build.py`, `params.json`, `examples/` | User entry point and reproducible input configurations. |
| `spirob/geometry.py`, `sections.py`, `collision.py` | Canonical geometry, cross-sections and collision construction. |
| `spirob/pipeline/` | CSV, STL, MJCF and CAD stages; normally called through `build.py`. |
| `spirob/parameters.py`, `xml_tools.py`, `mesh_assets.py` | Validation, safe XML editing and shared mesh mapping. |
| `tools/`, `fabrication/` | User inspection/tuning tools and print splitting. |
| `site/` | Static designer, shared parameter schema and browser presets. |
| `tests/`, `dev/` | Regression tests, independent legacy reference and browser/figure checks. |
| `docs/figures/`, `docs/engineering/` | README illustrations and detailed engineering history. This README is the current user guide. |
| `build/` | Generated models, reports and downloads; ignored by Git. |
| `pyproject.toml`, `uv.lock` | Supported environment and reproducible dependencies. |

The former root-stage scripts moved to `spirob/pipeline/`; use `build.py` instead of invoking those stages by path. `design_gui.py` now opens the browser designer. The old touch script and XML updater are replaced by the tools above. Duplicate DOCX/HTML/manual versions and requirements lists were removed. Old engineering reports are explicitly marked historical. Existing ignored root outputs are not deleted automatically; the new default build location is `build/spirob`.

For contributor changes, create a branch, run relevant tests, review `git diff`, commit source changes explicitly, and submit a PR. Do not commit generated model folders or `.venv`. The locked environment is intended for this repository checkout; installing an arbitrary standalone wheel is not the documented workflow.

## Scope and attribution

This is an independent MIT implementation extending the geometry and naming conventions of this repository. The original design and research are credited to [Zhanchi Wang, Nikolaos M. Freris and Xi Wei](https://arxiv.org/abs/2303.09861); their [Open-Spiral-Robots repository](https://github.com/ZhanchiWang/Open-Spiral-Robots) remains a separate project with its own license. Its noncommercial source is not incorporated here. CADQuery/OpenCascade, MuJoCo and other dependencies retain their respective licenses.

Remaining physical work includes experimental stiffness/damping identification, printed-part inertia calibration, and contact validation in deep concavities. The current n-lobe CAD path retains individual solid construction: extending shared-solid reuse showed small numerical volume differences and is deferred until independently resolved.

## Downloadable design and build records

Every successful `build.py` run now saves `design_report/report.md`, its figures,
a self-contained `design_report/report.html`, and a portable `design_report.zip`
inside the output directory. This also applies to the local designer's model ZIP
and the **Generate SpiRob model** GitHub Actions artifact. No extra flag or Node
installation is needed for terminal report generation.

```bash
uv run python build.py --params params.json --no-preview --output-dir build/my-spirob
xdg-open build/my-spirob/design_report/report.html
```

The HTML copy includes **Print / Save as PDF**. Select **Save to PDF** in the
browser print dialog. For Markdown, keep `report.md` beside its `figures/` folder;
share `design_report.zip` to preserve those links.

On the website, click **Download design report** beside **Copy JSON**. This works
on GitHub Pages without a Python server. Extract the downloaded ZIP and open
`report.html` or `report.md`. It records the selected link/station and current
label, core overlay and camera settings; turn on the annotations you want before
exporting. It includes the exact current SVG views and a 3D snapshot.

The website-only download is labelled **design preview** because no model build
has run. The report in a generated model ZIP is a **completed build record**:
resolved JSON includes command-line overrides, while joint gains and timestep
are read from the compiled MJCF. Terminal figures show actual simulation meshes,
representative mid-sections, core reference dimensions, spiral and gains; they
are not screenshots of a user's browser camera or fabrication hole verification.
Both records include creation time, parameter SHA-256, spiral constants and
modelling assumptions. Completed reports also include source revision and
`output_checksums.json`, identifying the generated files. Subsequent manual XML
or CAD edits do not revise the original report.

After applying this update, deploy **Deploy SpiRob designer → Run workflow → main**
to publish the new report button. Updating the repository alone does not publish
the website.

## Two-cable constant thickness (parallel flat faces)

On the website choose **2 cables · rectangular**, then under **Cross-section**:
set **Axial thickness law → constant**, disable **Base centre thickness automatic**,
and enter the desired thickness in mm. For example, 3 mm gives a 3 mm Y thickness
at the base, every intermediate link, and the tip. The side profile, cross-section,
3D preview, JSON and downloadable report all reflect this selection.

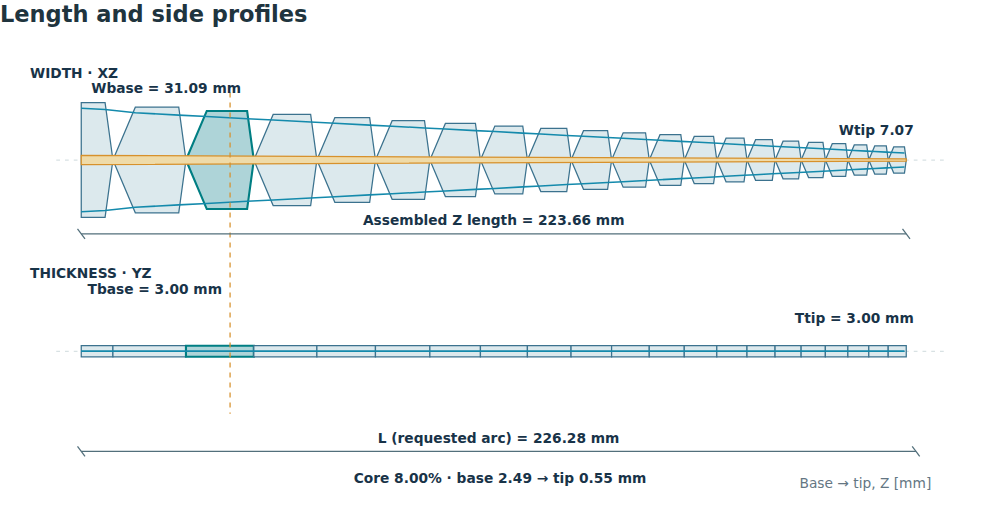
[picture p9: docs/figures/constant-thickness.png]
Constant 3 mm thickness: the YZ faces stay parallel while XZ width tapers


```bash
uv run python build.py --params examples/params-two-cable.json \
  --thickness-profile constant --base-thickness-mm 3 \
  --cad --iges --no-preview --output-dir build/flat-3mm
```

This applies to simulation meshes, collision hulls, and fabrication STEP/STL/IGES.
Shared meshes retain their full Y thickness and scale only in X and Z.
`constant` is different from `stepped`: stepped links become thinner toward the
tip. The XZ width taper, slits and percentage-based core X width still narrow
normally. Rectangular sections give parallel flat outer faces; a hex section
retains its transverse ridges, with constant centre and edge thickness along Z.
Automatic thickness uses the base width as the constant thickness.

Joint gains remain independently configured. Constant Y thickness breaks the
all-dimensions-similar assumption behind cubic stiffness scaling; calibrate the
gains for the manufactured design rather than treating the existing exponential
law as a consequence of this geometry. Deploy the updated website after merging.

## Cable bores and the partial base link

Fabrication holes now use **one straight cylindrical cut per cable**, connecting
that cable's first and last simulation routing anchors and extending to the base
and tip planes. The old round-transition sweep followed every simulation routing
segment and could introduce curved transition patches near the partial base.
The cutter now extends only a small diameter-dependent clearance beyond the ends.

The simulation's existing routing sites and dynamics are retained. They can
therefore differ from the straight manufacturing axis, especially at a partial
base. The CAD report records the maximum route deviation and both bore endpoints;
this difference matters when comparing hardware to an existing calibrated model.
Regenerate the CAD to apply the change; old downloads are unchanged.

With a positive **Cable hole diameter**, the website's **Cable holes** checkbox
shows bore openings in the cross-section and 3D preview and brown dashed straight
axes on the side profiles. Blue **Simulation routes** remain independently
switchable. Select **End** to see the openings. The 3D preview omits interior bore
wall shading; the STEP/STL/IGES files contain the full cylindrical walls.

Checks now include full-length bore-probe intersection on STEP, centre/ring ray
checks on STL, a single connected STL component and tighter tessellation around
small bores. IGES uses trimmed BRep export, with all six bounding coordinates and
face count checked after reimport. CAD topology checks do not certify print
settings, support generation or hole fit after printing.

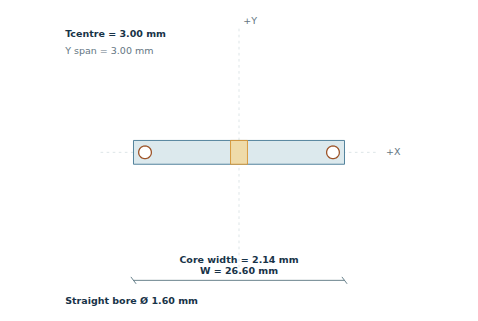
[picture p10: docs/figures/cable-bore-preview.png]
Website cross-section showing the straight fabrication bores


See [the bore update notes](docs/engineering/CABLE_BORE_UPDATE.md) for the route definition, export checks and findings from the supplied CAD files.

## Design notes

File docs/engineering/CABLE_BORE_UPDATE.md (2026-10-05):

# Straight fabrication bores and trimmed IGES export

The prior fabrication exporter swept a circle around every MJCF routing point
with round transitions. Exact-length designs include a partial base, and its
routing anchor does not lie on the continuation of the complete-link route.
Round transitions introduce small revolution surfaces near that kink. Cutter
extensions were one entire robot length, leaving remote analytic surface origins.

The manufacturing route now uses the first and last routing anchors to define a
single straight axis, extrapolated to the base and tip planes. Each bore is cut
with one cylinder, extending only a diameter-dependent clearance past the ends.
The MJCF route is not silently changed: changing it affects tendon lengths,
moment arms and calibration. CAD reports record the difference in millimetres.

Validation now checks a full-length 99.9%-diameter probe in STEP and IGES, and
33 centre/ring rays through each STL bore up to 95% of its diameter. STL tolerance
is capped at 0.5% of the bore diameter. Disconnected STL components are rejected.
IGES uses mode 1 (trimmed BRep) and validates face count, solid count and all six
bounding coordinates on reimport, not just the three bounding-box extents.

The website displays the same axes, true elliptical XY bore intersections, and
3D face openings. The sampled 3D display omits internal bore-wall shading and is
not a substitute for the checked fabrication exports. Brown marks are bores;
blue marks are the independent simulation routes. Hole visibility does not
depend on the simulation-route checkbox. End view is oriented consistently with
the XY cross-section; coincident base/tip labels are suppressed.

## Uploaded-file diagnosis

The inspected STEP was one valid solid; its STL was one closed connected volume.
The IGES contained 298 trimmed faces and no face outside the same model bounds.
There were no detached spherical solids. Six small revolution transition patches
occurred around Z = 9.99 and 18.27 mm. Two base-hole cylinder surface origins were
at Z = -227.109 mm, despite their trimmed faces being within the robot.
Displaying untrimmed support geometry can therefore explain the reported remote
cylinders, but this depends on the importing CAD application.

Sampled centre lines of the base-region cylindrical segments were open in the
supplied STEP. The physical print blockage is not conclusively diagnosed from
these files: it must not be reported as a proven pair of solid spheres. The
uploaded params.json and slicer project were not supplied. Regenerate from the
original JSON to reproduce the exact design with the new bore construction.

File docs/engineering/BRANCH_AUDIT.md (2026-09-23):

> Historical audit for 090665f. For the 23 September tapered-core correction, see ELASTIC_CORE_UPDATE.md and the current README.

# Branch audit and designer handoff

Review base: `ad64c019504bbfcd32a7e879e224cb3c8105b9d3` on `fix/consolidation-cad-workflows`.

This report records the current cleanup. The [README](../../README.md) is the user guide; other reports in this folder describe earlier work. The review is prepared for the branch, without merging `main` or publishing the site.

## Main and branch inventory

Remote refs checked on 19 September 2026: `main` is `55cc5f10594f9ada18d21b872e4d13fbc266e064`; the published working branch is `ad64c019504bbfcd32a7e879e224cb3c8105b9d3`. Main is an ancestor of the working branch (13 earlier feature/fix commits), with no main-only commits at that check. Its scattered root generators, duplicate guides and touch utilities are covered by this cleanup. There is no second independent set of changes to reconcile.

This update changes the review branch. Main acquires the organized layout when that branch is merged; it has not been rewritten remotely. Re-fetch before merging because later remote work may change this relationship.

## Findings addressed

| Finding | Change | Evidence / limit |
| --- | --- | --- |
| Hidden target site remained in XML | Removed target emission, configuration and marker CLI; legacy JSON is migrated with a notice. | Generated MuJoCo models have no named `target`; rejection of removed flag is tested. |
| Root mixed generators, tools, duplicate helpers and documentation | Production stages moved to `spirob/pipeline`; tools consolidated under `tools`; old geometry oracle retained under `tests/reference` only. | Imports and regression fixtures updated; full suite runs from a fresh locked environment. |
| Several dependency files and locally ignored packaging metadata | One `pyproject.toml` and public-PyPI `uv.lock`. | Python 3.12, MuJoCo 3.3.5, CADQuery 2.6.1. Clone/editable workflow; arbitrary wheel distribution is not claimed. |
| Optional build settings were not all reproducible from JSON | Added a validated `build` object, explicit CLI precedence, and resolved build settings in the output JSON. | Tests cover CLI override of CAD/IGES and collider settings. |
| Weak type/range checks and unknown JSON keys | Shared schema/field catalogue plus Python validation; cross-field geometry validation retained. | Boolean-as-number, non-finite values, bad vectors, misspellings and unsupported combinations rejected. |
| Repeated array copies inside every STL link adapter | Get all inverted quads once outside the loop. | Removes repeated whole-chain copying without changing CSV numeric provenance. |
| Preview cache depended on object identity and retained stale geometry | Bounded value-keyed cache. | Mutated parameter dictionaries no longer reuse the previous geometry. |
| Two-cable CAD rebuilt every geometrically similar complete link | Construct the two source solids and scale/translate complete links; special handling for the partial base. | Measured 21 → 2 constructions for a standard two-cable model. n-cable reuse deliberately deferred; see below. |
| A valid zero-notch input attempted a zero-radius CAD cut | Skip the cutter when notch ratio is zero. | Compiled simulation plus STEP/STL/IGES workflow tested with a zero-notch three-cable robot. |
| Old CAD could survive a later non-CAD build | Successful rebuild removes superseded optional CAD/MJB products transactionally. | Regression rebuild verifies no stale CAD and a loadable replacement XML. |
| Original touch editing script discarded existing sensors | New `tools/add_touch_sensors.py` preserves sensors, validates unique names, rebases paths and verifies physical properties. | Existing frame-position sensor and masses/inertias remain unchanged; duplicate sensor insertion fails without writing output. |
| CLI flags omitted useful explanations | Added descriptions for all explicit arguments. | Every user/pipeline entry point was exercised with `--help`; no undocumented explicit arguments found. |
| Manuals and GUI did not connect inputs to shape | One current illustrated README and a schema-driven web designer. | Front/side slices, selected-link XY section, polar view, constants, gains, 3D view, valid JSON import/export. |
| Export button could imply unsupported in-browser CAD | Local Python service and explicit static-hosting mode; optional manual GitHub Actions generator. | Real browser-driven download contains compiled XML/assets and STEP/STL/IGES. Pages hosting itself executes no Python. |
| Geom-count audit counted visual and contact meshes as separate links | `inspect_model` distinguishes unique links from mesh geoms checked. | Report semantics corrected without changing model geometry. |

## Measured efficiency result

One local run of **link-solid assembly only**, with the standard 21-link two-cable configuration:

| Metric | Prior construction | Shared construction |
| --- | ---: | ---: |
| OpenCascade link-solid constructions | 21 | 2 |
| Wall time | 2.681 s | 0.370 s |
| Sum of link volumes | 64193.98983675828 mm³ | 64193.98983675822 mm³ |

Maximum bounding-coordinate difference: 5.7e−14 mm; relative summed-volume difference: 9.1e−16. These are single-run observations, not a cross-platform benchmark or a claim about total export / simulation speed.

An analogous experiment on n-lobe CAD showed relative volume differences around 6.1e−6 (3 cables) and 1.1e−5 (4 cables), despite essentially identical bounds. That optimization is **not enabled**. Native n-lobe solids continue to be built individually until the difference is explained.

Shared simulation STL generation and cached convex-hull construction remain in use. Reducing the number of colliders helps contact-pair complexity, but this change does not remove physically necessary manifold contacts, alter friction, or guarantee real-time execution at a 0.0001 s timestep.

## Verification

Local locked-environment result: **358 passed, 19 skipped, 1 xfailed** in 250.25 s. Fifteen warnings are CADQuery/pyparsing deprecations, not numerical-instability reports.

- **1 strict xfail:** F08, the retained distal-site `−dz tan(φ/2)` correction does not satisfy the alternative constant-offset property. It is documented and should remain visible until the routing rule is deliberately changed and calibrated.
- **16 skips:** n-cable combinations outside the legacy two-cable compound collider's supported domain.
- **3 skips:** non-legacy profiles excluded from a benchmark defined for stepped rectangular links. Separate convex tests cover the newer shapes.
- **24 browser/Python configurations:** constants, requested/effective/chord lengths, all quad coordinates, all cable routes, and two-cable thickness endpoints agree within the declared tolerances (2e−13 m for coordinates).
- **2,412 CAD probes:** points ±0.003 mm around browser cross-section boundaries classify correctly inside/outside OpenCascade solids. Covers two-cable hex, three-cable notched and four-cable zero-notch models; base, complete and tip links at three stations. These samples do not certify every permitted combination.
- **Real Chromium interaction:** parameter edits, invalid input, selected-link slices, JSON download/import, persistence, old-target removal, mobile overflow, a static project subpath, and a completed XML/STL/STEP/IGES download.
- **CAD checks:** STEP solid reimport, positive/closed STL, volume/bounds reports, IGES surface reimport with mm units and 0.01 mm bounding-length tolerance.

Reproduce with `uv run pytest -q`, `uv run python dev/check_web_geometry.py`, `uv run python dev/check_web_sections.py`, and `node dev/browser/check.mjs` after installing its pinned browser dependencies. The README gives the exact commands. GitHub workflows are prepared but have not been run or deployed on the remote repository as part of this handoff.

## Remaining engineering work

1. **Physical calibration:** the exponential gain law, density and motor assumptions are not identified from printed hardware. Fabrication channels/cores are not automatically folded into simulation inertia. No new calibration claims are made.
2. **Concave contact:** n-cable convex hulls bridge notches. One hull can yield several contact points; regional force aggregation is available but cannot infer a unique point-load distribution.
3. **Preset cleanup:** legacy preset names and values remain for compatibility, including coarse timesteps if `post_gen.timestep` is omitted. Current examples explicitly set 0.0001 s. A future breaking release can simplify these presets after comparing dynamics.
4. **Separate elastic layer:** current fabrication exposes core width/diameter, not an independent axial layer thickness. The UI labels the actual supported dimension.
5. **n-lobe CAD reuse:** investigate the numerical volume differences before enabling the optimization.
6. **Preview limits:** the site samples surfaces and XY clearance, with a 32-cable / 400-link interaction limit. Exact solids, full 3D wall thickness and arbitrary deformed-contact states require the appropriate CAD/simulation tools.
7. **Cross-platform support:** automated workflow targets Ubuntu; the browser was exercised in Linux Chromium. Windows/macOS package and GUI behavior were not validated here.

The audit separates measured improvements from those deferred items; it does not assert that every possible configuration is optimized or physically validated.

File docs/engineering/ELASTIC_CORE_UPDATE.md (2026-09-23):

# Elastic core correction — 23 September 2026

The earlier n-cable fabrication core had constant diameter, and the two-cable core had constant X width. Both contradicted the requested local-width scaling. The default is now a 5% core, continuously tapered with the reference width used by the straightened model. STEP, STL and IGES use the same fused CAD shape.

## Parameter contract

- `build.elastic_core_percent` / `--elastic-core-percent`: finite number strictly between 0 and 100; 5 means 5%.
- The reference is the continuous pre-notch, pre-slit straightened width envelope, normalized at the base and extended to the geometric virtual apex.
- Two cables: core X width varies; core Y thickness follows the chosen link thickness and ridge profile.
- n cables and plain circular comparison: conical core with diameter proportional to reference width.
- Legacy `neck_width_mm` is migrated to a percentage preserving the base dimension. It no longer creates a uniform core. Conflicting definitions are rejected.
- Existing joint coefficients, their exponential index law and the protected base remain unchanged. The README explains both the geometric scaling motivation and the need for physical identification.
- Simulation mass/inertia and contact geoms do not automatically include fabrication cores or drilled channels.

## Original source definition

Upstream `ZhanchiWang/Open-Spiral-Robots` at `f563e69f292a6b8cac1946dc45ad9e60d8795391`, DesignTool's elastic-geometry definition, scales the half-taper angle. Its effective width ratio is tan(p φ/2)/tan(φ/2), with p a fraction. This update follows the user's explicit width-percentage definition instead. The algorithms here are independently implemented, not copied from upstream.

## Verification

`tests/test_elastic_core.py` covers continuous axial taper, geometric complete-link ratios, the partial-base case, input migration, browser/Python dimensions, and actual section measurements on reimported STEP, IGES and STL. The 2-, 3- and 4-cable export fixtures include drilled channels; their XML joint gains are checked against the existing exponential law. IGES is a surface representation and is intersected directly with a plane, not treated as a solid.

Validation result: **380 passed, 19 skipped, 1 expected failure** in the full Python suite; the 22 focused core tests passed independently. Browser workflow checks passed, including live percentage editing, narrowing sections, legacy migration and actual XML/STL/STEP/IGES ZIP download. Browser/Python geometry parity passed across 24 configurations. The skips and expected tendon-routing failure are existing documented cases.

Full-sized 21-link 2-hex, 3- and 4-cable examples have also been generated with STEP/STL/IGES. At 5%: base c = 1.554378713 mm; tip c = 0.346183139 mm. No mass, damping identification or print-strength conclusion follows from successful CAD topology checks.

Reproduction:

```bash
uv run pytest -q
uv run python dev/check_web_geometry.py
node dev/browser/check.mjs
uv run python dev/render_core_figures.py
```

`render_core_figures.py` expects `build/core-two`, `build/core-three`, and `build/core-four` generated with `--cad --iges`. All tools, examples and verification logs are included in the handoff. GitHub Actions and Pages must run again after the update reaches the chosen deployment branch; no remote publication is performed by the local bundle.

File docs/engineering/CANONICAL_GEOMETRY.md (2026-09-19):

> Engineering history. For current commands, parameters and supported workflows, use the [main README](../../README.md).

# Canonical Geometry Layer

`spirob/geometry.py` holds the one authoritative geometric description of a
SpiRob. It is computed once and consumed by everything downstream. No consumer
may re-derive spiral maths.

The layer imports only the standard library and NumPy — never matplotlib,
MuJoCo, CadQuery, Qt or VTK — so it stays importable in a headless, CAD-free
environment. Enforced by `test_canonical_layer_has_no_heavy_dependencies`.

---

## Quick start

```python
import json
from spirob.geometry import from_params

geo = from_params(json.load(open("params.json")))

geo.units[0].link_name              # 'link_001' — base, largest
geo.units[-1].link_name             # 'link_021' — tip, smallest
geo.lengths.discrete_chord_length_m # what the built chain measures
geo.tendon_path(0).routed_polyline()
geo.to_manifest()                   # JSON-serialisable build manifest
```

Command line:

```bash
python tools/geometry_audit.py --params params.json
python tools/geometry_audit.py --params params.json --policy whole_units
python tools/geometry_audit.py --params params.json --compare-policies
python tools/geometry_audit.py --params params.json --out build/manifest.json
```

---

## Conventions of record

All of these are stated once, in the `spirob/geometry.py` module docstring, and
asserted by `test_module_documents_the_conventions`.

| Question | Answer |
|---|---|
| Units | SI throughout — metres, radians. A name ending `_deg` or `_mm` is the only exception. `params.json` keeps its degree keys and is converted at the boundary. |
| Is `phi` a half-angle? | **No.** `phi` is the FULL included taper angle. The half-width slope is `tan(phi/2)`. `taper_angle_deg` is accepted as an alias. |
| Angle direction | `theta` increases counter-clockwise from +X. |
| `theta = 0` | The **tip** — smallest radius. |
| `theta = q0` | The **base** — largest radius. |
| Link order | `units[0]` is `link_001`, the base. Matches the CSV and MJCF. |
| Spiral order | `units_tip_to_base[0]` is `theta = 0`, the tip. |
| Relation | Exact reverses: `link[k] = spiral[N-1-k]`. Both indices are stored on every `UnitRecord`; never infer ordering from a name. |
| Reported lengths | Three distinct fields, plus two named effects — see "The three lengths" below, and §0 of `docs/GEOMETRY_AUDIT.md`. Arcs and chords are never conflated, and partial-unit completion is never conflated with arc-versus-chord shortening. |
| Tendon points | Defined once here, in the inverted (CSV) frame, in two stages: `attachment_m` on the surface, `routed_m` after shift and correction. |

### Field naming

Every dimensional field declares its unit in its name (`_m`, `_rad`, `_deg`,
`_rel`). Enforced by
`test_every_dimensional_field_carries_its_unit_in_its_name`.

### Tolerances

`Tolerances` is a documented, overridable dataclass:

| Field | Default | Meaning |
|---|---|---|
| `angle_rad` | `1e-9` | angles closer than this are equal; decides whether a partial unit exists |
| `length_m` | `1e-12` | lengths closer than this are equal |
| `solver_rel` | `1e-12` | relative convergence target |
| `solver_max_iter` | `200` | hard iteration cap; exceeding it raises |

---

## What `Invert_pose()` does, and why it is correct

`helper_functions.Invert_pose(quads, Length)`:

1. reflects `y` about the requested continuous length: `y -> -y + Length`
2. permutes vertex slots `[0,1,2,3] -> [1,0,3,2]`
3. reverses the element list

The result is the intended physical arrangement: largest at the base, smallest
at the tip.

**When the requested length does not contain a whole number of nominal units,
the partial unit is the last spiral interval, and after `Invert_pose()` it
becomes `link_001`, the base link. This is correct by design and is preserved.**
It is not an inversion or ordering error. Moving the partial unit to the tip
would invert the size ordering the design depends on.

The partial unit is partial in **angular span**, not small in **radius**: with
the committed defaults `link_001` spans 12.5452° yet remains at the
large-radius, wide end at 31.0876 mm. The smallest element, `link_021`, remains
at the tip and is complete.

Step 1 anchors the **tip** at exactly `y = requested_length_m`. The base
therefore sits at `requested - discrete`, exposed as
`BaseFrame.origin_offset_m`. With the committed defaults that offset is
2.6246 mm, and it is **the continuous-arc versus discrete-chord difference** —
the same quantity as the chord deficit below, surfacing in the frame because the
tip is the anchored end. It is not an accidental root displacement and the
geometry is not to be shifted by it.

It does not reach the simulation either: `csv2xml.py` establishes the simulated
root pose from `post_gen.robot_pos`, overriding the CSV-frame root position
entirely. On the built model `link_001` sits at exactly `[0, 0, 0.22628]`.

---

## Terminal unit policy

```json
{ "terminal_unit_policy": "exact_requested_length" }
```

| Value | Behaviour |
|---|---|
| `exact_requested_length` | **Default.** Preserves the requested continuous length exactly. Permits one partial unit at the base. Byte-identical to pre-Phase-2 output. |
| `whole_units` | Extends the spiral forward to the next complete nominal unit boundary. Never shortens. No partial unit. Reports the excess. |

Omitting the key selects the default, so every existing `params.json` keeps
working unchanged.

### Measured comparison, committed defaults

`L = 226.28 mm`, `d_tip = 7.139 mm`, `phi = 6.3°`, `Delta_theta = 30.78°`

| Quantity | `exact_requested_length` | `whole_units` |
|---|---:|---:|
| requested continuous (mm) | 226.2800 | 226.2800 |
| effective continuous (mm) | 226.2800 | 239.2515 |
| discrete chord (mm) | 223.6554 | 236.3856 |
| completion delta (mm) | +0.0000 | **+12.9715** |
| completion delta (%) | +0.0000 | **+5.7325** |
| chord deficit (mm) | −2.6246 | −2.8658 |
| chord deficit (%) | −1.1599 | −1.1978 |
| units total | 21 | 21 |
| complete units | 20 | **21** |
| partial unit | True | **False** |
| partial span (deg) | 12.5452 | 0.0000 |
| effective `q0` (rad) | 10.9632 | 11.2815 |
| nominal root width (mm) | 32.0449 | 33.4726 |
| realized root width (mm) | 31.0876 | **30.8119** |
| realized tip width (mm) | 7.0733 | 7.0733 |

Two results here are worth reading carefully.

**Both policies produce 21 units.** `whole_units` does not add a unit; it
*completes* the one that was partial. That is why the length grows 5.73 % while
the unit count is unchanged.

**`whole_units` raises the nominal root width but lowers the realized one**
(32.0449 → 33.4726 nominal, 31.0876 → 30.8119 realized). This is not a bug. Per
F-06 each straightened unit is a constant-width block, and its realized width is
evaluated at the unit's tip-side boundary with the chord sagitta factor applied.
Under `exact_requested_length` the base unit spans only 12.5452°, so its sagitta
factor is 0.99966 and realized ≈ nominal. Under `whole_units` the base unit
spans the full 30.78°, so the factor drops to 0.9908 and the block comes out
narrower — even though the continuous spiral now extends further.

The consequence for fabrication: `nominal_root_width_m` is the width the
*continuous* spiral reaches at `q0`, which no printed block ever realizes. Use
`realized_root_width_m`.

---

## The three lengths

Unit completion and arc-versus-chord shortening are **different effects** and
are reported separately. Never add them into a single "error".

```
requested_continuous_length_m    what the user asked for
    │
    │  completion_delta_m / _rel      <- unit-completion effect
    │                                    zero under exact_requested_length
    ▼
effective_continuous_length_m    spiral arc actually generated
    │
    │  chord_deficit_m / _rel         <- arc-to-chord effect
    │                                    always negative, O(Delta_theta²)
    ▼
discrete_chord_length_m          what the built link chain measures
```

`LengthReport.requested_vs_discrete_m` gives the total the user experiences, if
a single number is genuinely wanted.

---

## Widths

`nominal` comes from `d(theta) = a*(E-1)*exp(b*theta)`. `realized` is what
straightening actually produces:

```
realized_width = d(theta_start) * dist(O, chord) / r_c(theta_start)
```

The sagitta factor is `< 1`, so realized is always smaller. Both are reported;
fabrication should use `realized`.

---

## Deferred: dovetail and slit fabrication requirements

**Not implemented in Phase 2.** No solids are built. What Phase 2 provides is
stable, named reference geometry so a later CAD phase can consume it without
re-deriving anything.

### Anchors available today

| Anchor | Type | Purpose |
|---|---|---|
| `SpiRobGeometry.base_frame.mount_plane_point_m` | `(x, y, z)` | the flat face a dovetail or mount plate attaches to |
| `SpiRobGeometry.base_frame.mount_plane_normal` | unit vector | outward normal of that face |
| `SpiRobGeometry.base_frame.root_width_m` | metres | realized outer width at the mounting face |
| `SpiRobGeometry.base_frame.origin_offset_m` | metres | where the base sits on the inversion axis |
| `UnitRecord.slit_reference_m` | `(x, y, z)` | centre of the boundary between this unit and the next one toward the tip — where the compliant slit goes |
| `UnitRecord.slit_normal` | unit vector | slit plane normal, along the unit's local axis |
| `UnitRecord.local_frame_origin_m` / `local_frame_axis` | | per-unit placement frame |
| `TendonPoint.attachment_m` / `routed_m` | `(x, y, z)` | channel centreline for printed tendon holes |

Slit references are ordered base-to-tip and strictly increasing in `z`
(`test_slit_references_are_ordered_base_to_tip`). There are `n_units` of them;
the last one is the tip face.

### Parameters a later phase must add

None of these exist yet. They belong in a `fabrication` block in
`params.json`, defaulting to disabled so existing files keep working.

**Dovetail (base)**

| Parameter | Notes |
|---|---|
| `dovetail_enabled` | default `false` |
| `dovetail_width_m`, `dovetail_depth_m`, `dovetail_height_m` | nominal envelope |
| `dovetail_flare_deg` | included flare angle of the tail |
| `dovetail_clearance_m` | per-face clearance; **must be measured, not guessed** |
| `dovetail_fillet_m` | stress relief at the root |

**Slits (inter-unit compliance)**

| Parameter | Notes |
|---|---|
| `slit_enabled` | default `false` |
| `slit_width_m` | kerf; interacts with nozzle diameter |
| `slit_depth_fraction` | depth as a fraction of local realized width |
| `slit_profile` | `straight` \| `filleted` \| `keyhole` |
| `slit_count_per_unit` | 1 for two-cable, possibly `n_cables` for radial designs |

**Tolerances**

| Parameter | Notes |
|---|---|
| `linear_tolerance_m`, `angular_tolerance_deg` | tessellation |
| `printer_build_volume_mm` | split checking |

### Open questions requiring physical measurement

1. `dovetail_clearance_m` depends on printer and material shrinkage. The TPU
   cantilever free-vibration characterisation already done in this lab should
   set it, not a literature default.
2. `slit_width_m` and `slit_depth_fraction` determine achievable bend before
   self-contact. With `Delta_theta = 30.78°` the implied wedge angle is fixed
   by the geometry; whether a printed TPU hinge survives that range across
   21 units is empirical.
3. Whether the partial base unit is acceptable as a printed part, or whether
   `whole_units` should become the fabrication default. Purely a fabrication
   decision — the simulation default stays `exact_requested_length`.

---

## Migration status

| Consumer | Status |
|---|---|
| `tools/geometry_audit.py` | migrated — reporting comes from the canonical model |
| `preview.py` | migrated — private fork deleted, tendon points shared |
| `spirob_csv_generator.py` | not yet — still calls `helper_functions` directly |
| `csv2geom_nlobe.py` | not yet — reads the CSV |
| `csv2xml.py` | not yet — reads the CSV, computes routing independently. Its routing rule is reproduced exactly by the canonical layer; the rule itself is still undecided (F-08) |
| future STEP/STL exporter | will consume the canonical model from the start |

`helper_functions.py` is untouched and still works. The canonical layer
reproduces its output bit-for-bit
(`test_canonical_reproduces_legacy_curled_pose_exactly` and siblings), which is
what makes the remaining migrations safe to do one at a time.

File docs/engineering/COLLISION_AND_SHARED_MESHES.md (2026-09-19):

> Engineering history. For current commands, parameters and supported workflows, use the [main README](../../README.md).

# Collision geometry and shared source meshes

This change continues `fix/consolidation-cad-workflows` from `9b1513b`.
It preserves the accepted partial-base orientation and does not rebase geom axes.

## Inertia handling

Previously the capsule mode added a density-bearing capsule while only disabling
contact on the visual mesh. Both geoms therefore contributed to the compiler's
inferred body mass, centre of mass and inertia. Contact masks do not exclude
geoms from inertia calculations.

Generation now first compiles using only the group-1 mesh for each link's inertia.
It writes that body's mass (kg), centre of mass (m), inertial quaternion and
principal moments (kg m²) into an explicit `<inertial>` element. Every collision
proxy has `mass="0" density="0"` and belongs to group 3. The delivered XML uses
`inertiafromgeom="auto"`; it respects explicit link inertias while newly added
task objects can still infer their own. This follows MuJoCo's documented
[compiler inertia rules](https://mujoco.readthedocs.io/en/3.3.5/XMLreference.html#compiler-inertiafromgeom).

The inertias retain the existing mesh/density model (default 1200 kg/m³), not
measured printed-robot properties. Regenerate after changing geometry or density.
Do not force `inertiafromgeom="true"` in a containing task XML, since that would
override explicit inertias. `auto` also works when integrating the robot into a
larger scene. Tests add an ordinary 50 g task object and verify both its inferred
mass and the unchanged robot masses.

## Two-cable compound collision

The flat simulation link is an extrusion of its canonical XZ polygon along Y.
Its top and bottom slopes mean a single rounded rectangle would be a poor fit.
The new collider insets that polygon by the selected radius, then covers the
rounded outline with oriented edge boxes, corner cylinders along Y and interior
boxes. All primitives belong directly to the existing link body. No extra bodies,
joints or constraints are introduced.

The union stays inside the original CAD, retains tangent flat faces, and rounds
off convex corners. Front and back remain flat at the existing extrusion
thickness. It has no internal holes. This is a contact approximation of the
**simulation mesh**; the separate fabrication profile can have a different lens
section and flexures.

For `examples/params-two-cable.json` at the default radius ratio 0.04:

| Link | Primitives | Corner radius (mm) | Maximum inward profile gap (mm) | Profile area covered |
|---|---:|---:|---:|---:|
| Partial base `link_001` | 17 | 0.62175 | 0.25754 | 99.8776% |
| First complete `link_002` | 33 | 0.57252 | 0.18735 | 99.9646% |
| Tip `link_021` | 33 | 0.14147 | 0.04629 | 99.9646% |

The complete model has 677 collision primitives. MuJoCo processes overlapping
geoms individually: this is not a Boolean-fused collision solid, and overlapping
faces can generate multiple contact points. Contact count and solver cost should
be assessed in the actual grasping scene. Native MuJoCo 3.3.5 was tested here;
the user's mjlab training environment and its GPU backend were not tested.

Compound contact margins default to zero so the measured surface fit also
describes contact onset against zero-margin objects. A positive margin on the
robot or contacted object can cause contact before visible surfaces touch.

Rounded compound fitting is currently limited to the two-cable flat section.
Three or more cables retain mesh or massless-capsule contact options; a fitted
compound approximation of their lobes requires a separate design.

## Shared STLs

All complete canonical profiles are uniformly scaled copies of the first
complete link. Generation validates that similarity, exports one
`meshes/link_template.stl`, and preserves `link_NNN` asset names using individual
MJCF `scale` values. Partial units get their own STL; whole-unit designs need
only the template. The largest complete link is the reference, so scaling down
does not magnify its tessellation error. The separate base mounting geometry is
preserved.

MuJoCo still compiles a separate mesh asset for each scale. The saving is in
export work and source files, not a guarantee of reduced runtime mesh memory.
The legacy layout remains available with `--mesh-layout individual`.
Fabrication STEP/STL generation continues to build its own solids.

Compared with the previous individual-STL exports on the two supplied examples:

| Model | Previous mesh-derived total mass (g) | Shared-source total mass (g) | Largest per-link relative mass change |
|---|---:|---:|---:|
| Two cables | 25.84535955 | 25.84535991 | 0.00000995% |
| Three cables | 40.82149599 | 40.82395433 | 0.01937% |

Small differences are from sharing one tessellation instead of independently
tessellating each size. The three-cable total difference is about 0.0060%.
For a fixed mesh layout, changing between mesh/capsule/compound contact preserves
all body inertias to numerical precision. Tests compare inertia tensors in body
coordinates, since MuJoCo may reorder principal axes between scaled assets.

## Build and inspect

From the repository root, with the existing uv virtual environment:

```bash
source .venv/bin/activate
uv pip install -r requirements-dev.txt
python build.py --params examples/params-two-cable.json --no-preview --collision-mode compound --output-dir build/two-cable
python tools/inspect_collision.py --mjcf build/two-cable/spirob_physics_model.xml --view
```

Blue shows CAD; orange shows colliders. Geom groups 1 and 3 toggle them separately.
The inspection view does not integrate time; use joint sliders to examine poses.
To run dynamics, open the same XML directly:

```bash
python -m mujoco.viewer --mjcf=build/two-cable/spirob_physics_model.xml
```

To halve corner rounding, pass `--collision-corner-radius-ratio 0.02` to the build.
To set a 0.1 mm contact buffer, pass `--collision-margin-m 0.0001`. Rebuild into a
separate directory when comparing variants. The GUI's existing build action uses
the default mesh contact mode; select compound mode with the command above.

## Validation

The full suite passed 249 tests, with 16 inapplicable two-cable-only cases skipped
and the existing F08 tendon-routing expected failure retained. Focused collision
checks were repeated after the final compiler integration adjustment. They cover:

- Equal mass, centre of mass and inertia across collision modes, including after
  deliberately assigning a large mass to a collider in the XML.
- Unchanged body, joint, site, tendon and actuator interfaces and tendon lengths.
- Solid, contained profile coverage for every link, both terminal-unit policies,
  and corner ratios 0.02, 0.04 and 0.08.
- Native sphere and box contacts against flat faces and curved corners of links
  1, 2, 11 and 21, with separation checks and no mesh contacts in compound mode.
- Correct shared-source scaling, including mass cubed and inertia fifth-power
  scaling, and multi-robot array mass/asset preservation.
- Successful compilation of final two-, three- and four-cable example XML files.

These checks establish geometry and compiler behavior. They do not establish
grasp success or tune friction, tendon actuation, contact stiffness or material
properties for a particular experiment.

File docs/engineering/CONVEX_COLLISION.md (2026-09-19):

> Engineering history. For current commands, parameters and supported workflows, use the [main README](../../README.md).

# Convex collision

Select `--collision-mode convex` for one massless convex mesh collider per link.
This supports two-cable rectangular/hex sections with linear/stepped thickness,
and n-lobe sections for three or more cables. It excludes `--plain` models.
Existing defaults and collision modes remain available. For n-cable examples,
notch approximation measurements and the target-marker change, see
[NCABLE_CONVEX.md](NCABLE_CONVEX.md).

The old compound model overlaps many boxes/cylinders on each rigid link.
MuJoCo solves contacts from their individual geom pairs; it does not Boolean
union their exterior surfaces. Those geoms do not add separate rigid bodies,
but their overlapping contact patches can add many redundant constraints.

The new mode takes the convex hull of the actual generated simulation STL,
without vertex decimation, and embeds its hull vertices in XML. Collision
assets use the same scale and body frame as the visual CAD. No extra STL files
are needed: the complete links still share one STL and the partial base another.
Each `collision_NNN_hull` is group 3, mass/density zero; `gmesh_NNN` remains
group 1 and visual-only. Explicit CAD-derived body mass, COM and inertia,
joint gains, body/joint/site/tendon/actuator names and cable paths are preserved.

MuJoCo's previous `mesh` mode also collided with a convex hull. This update is
not a new triangle-by-triangle collision engine. It makes a separate, visible
hull asset, selects zero contact margin by default and enables native CCD plus
`multiccd` for surface contact support. One collider can still produce several
contact points. Friction, `condim`, cone, solver and body collision filters are
not changed. No artificial contact cap is introduced.

Reference: [MuJoCo 3.3.5 collision detection](https://mujoco.readthedocs.io/en/3.3.5/computation/index.html#collision-detection).
The native multi-point path requires zero margins on both contacting objects;
positive margins trigger MuJoCo's slower fallback. The flag is a global option
and therefore also applies to other compatible object pairs in the scene.

## Two-cable surface fit

Rectangular sections (including the continuous axial taper) and stepped hex
sections are convex and retain their CAD envelope to mesh precision. The old
compound's inward-rounded corners are replaced by the CAD's sharp corners.
This is deliberate; the new mode has no corner-radius parameter.

The linear hex section has slightly nonconvex ruled surfaces. A single convex
geom cannot represent those exactly. Its hull fills the shallow concavity.
For the supplied geometry with automatic base thickness (31.087574 mm):

| Link | Largest sampled surface gap, either direction | Extra volume |
|---|---:|---:|
| Partial base, link_001 | 0.02113 mm | 0.05711% |
| Largest full link, link_002 | 0.05844 mm | 0.17999% |
| Tip, link_021 | 0.01444 mm | 0.17999% |

These are sampled comparisons to the simulation STL, not certified maximum
errors or measurements of printed parts. Other thickness/shape settings need
their own fit check. A future exact nonconvex representation would need several
convex pieces or another collision method. Hulls also do not preserve cable
holes, recesses or spaces in a fused multi-link fabrication STL; this mode uses
the undrilled simulation solid of each individual link.

## Build and inspect

From the repository root:

```bash
uv pip install -r requirements-dev.txt

uv run python build.py --params examples/params-two-cable-hex.json \
  --base-thickness-mm auto --thickness-profile linear \
  --collision-mode convex --timestep 0.0001 \
  --no-preview --output-dir build/convex-hex

uv run python -m mujoco.viewer --mjcf=build/convex-hex/spirob_physics_model.xml

uv run python tools/inspect_collision.py \
  --mjcf build/convex-hex/spirob_physics_model.xml --view

uv run python tools/inspect_collision_surface.py \
  --mjcf build/convex-hex/spirob_physics_model.xml \
  --out build/convex-hex/surface.png --json build/convex-hex/surface.json
```

Use `examples/params-two-cable.json` for rectangular links. Replace `auto` with
your base thickness in mm. `collision_summary.json` is generated automatically.
The inspection viewer is frozen: blue is CAD, orange is the actual hull, and
groups 1/3 toggle them. Use the normal MuJoCo viewer to simulate actuators.

`inspect_collision_surface.py` samples each triangle on a barycentric grid,
measures nearest-surface distances in both directions, checks containment and
compares volume. It plots transverse cuts, not a misleading end-on projection.
The default selected links are the base, largest full link and tip. Use
`--links link_001 link_005` to inspect others.

## Contact and constraint measurements

Controlled comparison on the same 21-link **stepped rectangular** CAD and
inertias; largest complete link; prescribed 0.05 mm face overlap:

| Metric | Legacy compound | Convex |
|---|---:|---:|
| Robot contact geoms | 677 | 21 |
| Link against plane: contact points | 126 | 3 |
| Link against plane: scalar constraints | 504 | 12 |
| Link against box: contact points | 114 | 4 |
| Link against box: scalar constraints | 456 | 16 |
| Link against link: contact points | 740 | 4 |
| Link against link: scalar constraints | 2960 | 16 |

These are specific static patches, not counts promised for every pose.
`condim=3` with the existing pyramidal friction cone gives four scalar rows per
active contact here. Counts elsewhere can also include joint/tendon limits.

To reproduce the comparison without changing the CAD between the two modes:

```bash
uv run python build.py --params examples/params-two-cable.json \
  --thickness-profile stepped --collision-mode compound --timestep 0.0001 \
  --no-preview --output-dir build/compound-baseline
uv run python build.py --params examples/params-two-cable.json \
  --thickness-profile stepped --collision-mode convex --timestep 0.0001 \
  --no-preview --output-dir build/convex-comparison
uv run python tools/benchmark_collision.py \
  --baseline build/compound-baseline/spirob_physics_model.xml \
  --candidate build/convex-comparison/spirob_physics_model.xml \
  --json build/collision-benchmark.json
```

The benchmark rejects different CAD/inertias. It includes plane, box and
link-pair probes. Bounded dynamic checks are separate:

```bash
uv run python tools/inspect_collision.py \
  --mjcf build/convex-hex/spirob_physics_model.xml --stress \
  --controls -10 0 --seconds 5 --ramp-seconds 1 \
  --json build/convex-hex/stress-left.json
```

For the supplied linear hex model, five seconds each at targets `[-10,0]`,
`[0,-10]`, and `[-10,-10]`, with a one-second ramp and 0.0001 s timestep,
completed without MuJoCo warnings. The unilateral runs peaked at 22 contacts,
88 scalar constraints and 157,504 bytes of arena use. The symmetric run had
no contacts. The normal 14 MiB arena was sufficient; it was not increased.
These tests do not cover every object, impact or actuator history.

Multi-point contacts preserve surface support but do not guarantee perfectly
static resting contact: isolated flat mesh tests exhibited small rocking and
drift as the contact manifold changed. The regression checks bounded support,
not zero residual velocity. Sharp corners and slightly filled hex concavities
can also change contact normals compared with the old rounded compound.

## Locate forces without adding colliders

```bash
uv run python tools/inspect_contact_forces.py \
  --mjcf build/convex-hex/spirob_physics_model.xml \
  --seconds 2 --ramp-seconds 1 --controls -10 0 \
  --json build/convex-hex/contact-forces.json
```

The JSON lists solved contacts, their world and body-local positions, the
force **on** each link in both frames, and the summed force and moment about
its body origin. Cable loads and joint reactions are separate quantities.
Self-contact appears with opposite forces for the two participating links.

To sum contacts within 2 mm of a chosen point, add for example
`--body link_002 --point-local-m 0 0 0.01 --radius-m 0.002`. Coordinates are
metres in that link's body frame, with the joint origin at zero. The example
point is illustrative; choose coordinates from your model. Moments then use
that point as the reference. An empty region correctly reports zero contacts.

This reports discrete solver contacts, not a continuous pressure distribution
or a unique force at an arbitrary mathematical point. Contact indices change
between timesteps. Choose a body-local region rather than tracking an index.

For your existing simulation, import
`from tools.inspect_contact_forces import contact_report` and call it with the
live `model, data`. Ensure frames and forces describe the same pipeline state;
the CLI calls `mj_forward` after the final step. You can also save `qpos`,
`qvel`, `ctrl` with `numpy.savez` and pass `--state-npz state.npz` (this restores
those arrays, not every possible simulation state field). Force-frame/sign
tests check a supported sphere against its weight and equal/opposite forces
on a contacting body pair.

All inspection tools, tests and these instructions are included in the commit.
The full parameter manual and broader README rewrite remain deferred.

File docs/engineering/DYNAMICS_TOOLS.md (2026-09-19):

> Engineering history. For current commands, parameters and supported workflows, use the [main README](../../README.md).

# Inertia audit, joint gains and contact-memory diagnostics

The tools read standalone MJCF XML. `audit_inertia.py` is read-only.
`set_joint_gains.py` writes and compiles a separate XML, leaving the input intact.
`inspect_collision.py` provides a frozen viewer and a bounded headless test.

## What the reported crash means

The supplied log has 4,643 contacts and 18,572 scalar constraints. The native
MuJoCo arena stores dynamic contact/constraint arrays and temporary solver
storage. Running out of the latter causes the fatal stack-allocation error.
This is distinct from a QVEL, QPOS or QACC numerical-instability warning.
MuJoCo documents this behavior and the `maxuse_arena` diagnostic in its
[memory-allocation guide](https://mujoco.readthedocs.io/en/3.3.5/modeling.html#memory-allocation).

The earlier compound approximation has 677 collision primitives. Deep folding
can create many contacts between primitives on different links. Increasing
arena memory addresses allocation capacity; it does not change the contact
geometry or establish stable dynamics.

The historical tests below used the two-cable example with thickness/width
ratio 0.3 (before the new thickness=width defaults), unchanged gains and
inertias, a 2 ms timestep, and controls `[-10, 0]` from the initial pose:

| Run | Result |
|---|---|
| Existing 14 MiB arena, immediate control step | Fatal allocation error at about 0.666 s; 4,410 contacts and 17,640 constraints |
| 128 MiB arena, same immediate step | No allocation error before a QACC warning at about 5.994 s; peak 23,027 contacts, about 73.45 MiB arena use |
| 128 MiB arena, two-second ramp to the same target | QACC warning at about 5.802 s; peak 25,557 contacts, about 81.52 MiB arena use |
| 128 MiB arena, two-second ramp to `[-1, 0]` | Completed 12 s without warnings; this particular trajectory produced no contacts |

These are specific test sequences, not force limits or a stability envelope.
The regenerated model's inertias, gains, collision poses/sizes and actuator
ranges were also checked to be bit-for-bit equal to the earlier model.
The larger-arena run confirms that the memory fault and subsequent instability
can occur with the same inertia and gains. It does not identify a unique cause
of the instability. Contact overlap, timestep, actuation and joint gains all
remain relevant.

New compound builds allocate 128 MiB explicitly. Override using
`--arena-memory-mib N`. This is native MuJoCo memory per `MjData`; GPU backends
have their own allocation behavior. The report includes peak use, so allocation
can be chosen from measured contact-heavy tests. No contacts are disabled to
make the test pass.

## 1. Compare inertia in a consistent frame

MuJoCo stores a body's three principal moments in `body_inertia`, together with
the principal-frame orientation in `body_iquat`. Comparing just the three
numbers can be misleading when principal axes are permuted or rotated.

The audit resolves every tensor along axes parallel to the containing link's
body axes. The origin is at the centre of mass. If `R` maps the inertial axes
into body axes, the compiled tensor is

```text
I_COM_body = R @ diag(body_inertia) @ R.T
```

The report includes mass in kg, COM position in body coordinates in metres,
and the full symmetric 3 × 3 tensor in kg m². Each geometric reference has its
own COM, which is reported separately. For a common-origin comparison the tool
also shifts its tensor to the MuJoCo COM using the parallel-axis theorem:

```text
I_reference_at_MJ_COM = I_reference_at_own_COM
                       + mass * ((r @ r) * identity - outer(r, r))
```

Here `r` is the displacement between those COM locations, expressed in body
axes. The printed tensor differences use this common origin and orientation.
The JSON also retains every tensor about its own COM.

There are two independent geometric references:

- **Mesh:** signed triangle-volume integration using trimesh, excluding all
  collision proxies. Compiled mesh vertices are placed in body coordinates
  using the compiled geom pose, compensating MuJoCo's mesh centring/rotation.
  This checks the compiled body properties against the geometry it displays.
- **CAD:** OpenCascade volume integration of the simulation-profile solid
  reconstructed from the matching parameters. This avoids STL tessellation.
  CAD is integrated in mm, then mass and inertia are converted with factors
  `density × 10^-9` and `density × 10^-15`, respectively.

Both assume a homogeneous solid at the stated density. They are not measurements
of an infilled printed part. The CAD reference is the simulation profile, not
the fabrication assembly with flexures and optional cable holes.

Install the comparison dependencies in the existing uv environment:

```bash
source .venv/bin/activate
uv pip install -r requirements-dev.txt
```

Inspect selected links, using the parameters that produced the XML:

```bash
python tools/audit_inertia.py \
  --mjcf build/two-cable/spirob_physics_model.xml \
  --params examples/params-two-cable.json \
  --density 1200 \
  --links link_001 link_002 link_021 \
  --json build/two-cable/inertia_audit.json
```

Omit `--links` to audit every link. Omit `--params` for mesh-only comparison.
Add `--plain` only when the XML was generated with the plain revolved profile.
Add `--reference-mjcf path/to/older.xml` for a before/after compiled-inertia
comparison; both XMLs must use the same link-body coordinate convention.

For the supplied two-cable example, all 21 CAD tensors agree with MuJoCo to a
maximum relative Frobenius error of approximately `4.1 × 10^-8` at density
1200 kg/m³. This does not support a significant geometric inertia error in
that example.

The three-cable example shows a separate discrepancy: selected complete links
have approximately 3.04% higher compiled mass and 2.57% tensor difference from
the CAD reference. Its compiled triangle surfaces also fail the mesh reference's
closed/winding-consistent checks, so that reference is explicitly marked
unavailable rather than silently repaired. The existing MuJoCo 3.3.5 `legacy`
mesh-inertia algorithm can overcount non-convex geometry; see its
[mesh inertia documentation](https://mujoco.readthedocs.io/en/3.3.5/XMLreference.html#asset-mesh-inertia).
The audit reveals this discrepancy but does not change the model's inertias.
With any unavailable mesh reference, the tool writes the available report and
returns exit code 2. Parameters, density and geometry must be checked before
treating a CAD difference as a MuJoCo error.

## 2. Edit the flexible-joint gains

The existing generator law uses the numerical suffix `n` in `j_NNN`:

```text
k_n = K0 / beta**(3*(n-1))
d_n = D0 / beta**(3*(n-1))
```

The tool preserves that indexing by default and skips `j_001`. For `K0=0.2`,
`D0=0.01` and `beta=1.03`, `j_002` therefore receives `k=0.18302833` N m/rad
and `d=0.0091514166` N m s/rad. The protected base remains at its existing
values, 100 and 50 in the example.

To reproduce the current gain values while changing only arena capacity:

```bash
python tools/set_joint_gains.py \
  --mjcf build/two-cable/spirob_physics_model.xml \
  --out build/two-cable/spirob_arena128.xml \
  --stiffness 0.2 --damping 0.01 --beta 1.03 \
  --arena-memory-mib 128 \
  --json build/two-cable/gain_changes.json
```

For your next gain experiment, supply your chosen stiffness and damping and use
a new output filename. There is no automatically selected stable gain pair.
`--anchor first-flexible` instead assigns the entered coefficients directly to
`j_002`, then decays toward the tip. The printed formula states which convention
was used. `--exclude-joints` can name additional protected joints.

Hinge and ball joints are supported; a ball joint gets the same damping on all
three rotational DOFs. The tool checks the compiled output, verifies inertias,
geometry and the protected gains, and publishes only after verification. Asset
paths remain usable when writing into another directory. `--overwrite` permits
replacing an earlier output; overwriting the input is intentionally rejected.

This edits the XML, not `params.json`. To retain a chosen generator-indexed fit
across future builds, update these fields in `post_gen`:

```json
"joint_stiffness_base": 0.2,
"joint_damping_base": 0.01,
"joint_beta": 1.03
```

Keep `first_joint_stiffness` and `first_joint_damping` unchanged. For the
first-flexible convention, multiply both entered coefficients by `beta**3`
when storing them as the generator's base coefficients.

The protected base is a high-gain joint in the current XML, not a true welded
connection. Joint dynamics also involve downstream links through the coupled
mass matrix; an isolated link's COM tensor alone is insufficient to calculate
a guaranteed stable gain or damping ratio for the whole robot.

## 3. Inspect and check a candidate

Frozen comparison of CAD and colliders:

```bash
python tools/inspect_collision.py --mjcf build/two-cable/spirob_arena128.xml --view
```

Native simulation of that exact file:

```bash
python -m mujoco.viewer --mjcf=build/two-cable/spirob_arena128.xml
```

A bounded headless test, using controls in actuator order:

```bash
python tools/inspect_collision.py \
  --mjcf build/two-cable/spirob_arena128.xml \
  --stress --controls -1 0 --seconds 12 --ramp-seconds 2 \
  --json build/two-cable/stress_report.json
```

Use another target to test another actuation condition. The tool does not alter
gains, force limits, timestep or contacts. It stops at the first MuJoCo warning
or fatal error, saves the report and returns exit code 2 on failure. Reports
include peak contacts, constraints and arena use. An instability can reset
`data.time`; therefore the report separately records the attempted step's start
time, nominal completed-step duration and final data time.

## Checks included with this update

Regression tests check a rotated, offset box against its analytic full tensor;
CAD mm-to-SI conversion; detection of a deliberately doubled inertia; parallel
axis shifting; unchanged protected-base gains, mass and geometry; both indexing
conventions for hinge and ball joints; relocated asset paths; invalid-input
rejection; and allocation of a reproduced pose with over 4,000 contacts.

The high-force instability remains open. The new tools support controlled
comparisons before selecting gains or changing the contact approximation.

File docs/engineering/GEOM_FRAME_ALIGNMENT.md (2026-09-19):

> Engineering history. For current commands, parameters and supported workflows, use the [main README](../../README.md).

# Actual Geom-frame alignment — 10 September 2026

This follow-up preserves the accepted base surface correction in `4b464d2`.
The previous Body-frame viewer did not align Geom frames. The new opt-in path
aligns the actual `geom_xmat` axes returned by `mj_forward`, and the viewer uses
MuJoCo's real **Geom** frame display.

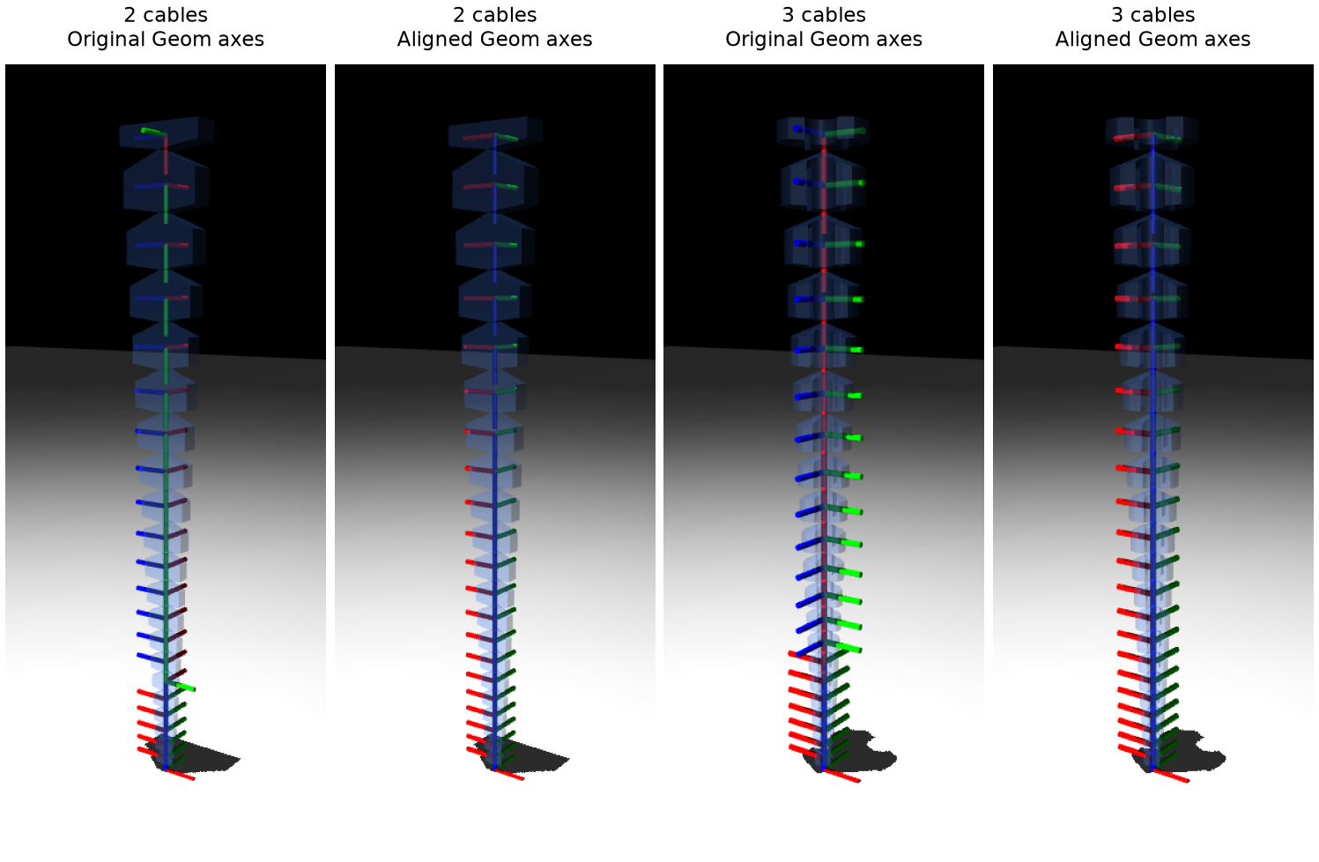
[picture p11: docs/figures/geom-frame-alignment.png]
Native MuJoCo Geom frames, before and after


## Cause and significance

The supplied examples reproduce these compiled local geom quaternions (wxyz):

| Model | Links | Quaternion, approximately |
|---|---|---|
| Two cables | 1 | (0, .7071, 0, .7071) |
| Two cables | 2–15 | (.5, .5, .5, .5) |
| Two cables | 16 | (.7071, 0, 0, .7071) |
| Two cables | 17–21 | (1, 0, 0, 0) |
| Three cables | 1–14 | (.5, .5, −.5, .5) |
| Three cables | 15–21 | (1, 0, 0, 0) |

MuJoCo 3.3.5 centres ordinary meshes and aligns their coordinates with computed
principal inertia axes. It compensates by changing the geom placement, so the
rendered mesh surface retains its authored pose. Its XML schema has no option
to disable this operation for ordinary mesh geoms. Setting `quat="1 0 0 0"` in
the source geom does not prevent it.
[MuJoCo mesh reference](https://mujoco.readthedocs.io/en/3.3.5/XMLreference.html#asset-mesh)

This frame difference alone does not mean that links, joints or collision
surfaces are physically misoriented. It matters to code reading `geom_xmat`,
geom orientation sensors, or vectors expressed in geom-local coordinates.
The frame's origin remains at the compiled mesh centre, while the body origin
remains at the link/joint origin. The alignment option changes orientation,
not these origins. During bending, each geom follows its own body; the entire
chain's axes should only be parallel in the straight reference pose.

The authors' repository tree does not contain a published simulation XML to
compare directly. No assertion is made here about their compiled model, and
none of their generator implementation was used for this repair.

## Implementation

`spirob.mujoco_frames.aligned_geom_model(model)` returns an independent compiled
model. For each standalone `link_NNN` mesh geom, with old local rotation R:

1. Replace compiled mesh vertices v with Rv and rotate vertex/polygon normals.
2. Rotate mesh BVH boxes conservatively and update geom bounds used by rays.
3. Set the actual geom quaternion to identity and update `geom_sameframe` to
   `BODYROT`. Leaving the old `INERTIA` shortcut would ignore the new quaternion.
4. Compensate `mesh_quat`, retaining the authored mesh-to-body relationship.

The world surface is preserved because `R_body R v` becomes `R_body (Rv)`.
Geom centres, body mass, inertial pose and diagonal inertia are retained.
Body BVHs are already in the unchanged body inertial frame. The original
bounding-sphere radius is retained because it remains valid under rotation
and controls the convex collision solver's relative tolerance.

Build-time CSV, STL, XML and CAD generation are unchanged by this option.
It does not flip links or alter tendon, site, joint or actuator definitions.

## Run it

From the generator checkout with its uv-managed environment active:

```bash
uv pip install --python .venv/bin/python -r requirements-dev.txt

# Inspect an existing XML, aligning actual Geom axes in memory:
python tools/inspect_model.py --mjcf build/two-cable/spirob_physics_model.xml --align-geom-frames --view

# Also save that aligned compiled model:
python tools/inspect_model.py --mjcf build/two-cable/spirob_physics_model.xml --align-geom-frames --save-mjb build/two-cable/spirob_aligned.mjb

# Or generate XML/STL and aligned MJB together:
python build.py --params examples/params-two-cable.json --no-preview --output-dir build/two-cable --align-geom-frames
python build.py --params examples/params-three-cable.json --no-preview --output-dir build/three-cable --align-geom-frames

# Inspect the saved model; no alignment flag is needed when reopening MJB:
python tools/inspect_model.py --model build/two-cable/spirob_aligned.mjb --view
python tools/inspect_model.py --model build/three-cable/spirob_aligned.mjb --view

# Run dynamics in the standard viewer; select Rendering > Frame > Geom:
python -m mujoco.viewer --mjcf=build/two-cable/spirob_aligned.mjb
```

The report prints both `Authored mesh/body rest frames aligned` and
`Actual Geom axes aligned with bodies`. Both should be `True` for an aligned
straight model. Omitting `--align-geom-frames` on an XML reports the original
misaligned Geom axes and returns exit code 1. `--json` gives per-link values;
`--frames body` explicitly requests Body frames in the viewer.

The GUI's **Inspect link frames** applies the alignment in memory and shows
Geom axes. Desktop interaction still needs workstation acceptance; offscreen
native MuJoCo rendering was checked in this environment.

For Python consumers running from this checkout:

```python
import mujoco
from spirob.mujoco_frames import aligned_geom_model

model = mujoco.MjModel.from_xml_path("build/two-cable/spirob_physics_model.xml")
model = aligned_geom_model(model)  # before MjData, renderer, or GPU conversion
data = mujoco.MjData(model)
mujoco.mj_forward(model, data)
```

## Boundaries

- **XML reload recompiles and restores the principal-axis frames.** Use the
  loader above or the optional `.mjb`. Do not convert the aligned model back to
  XML and expect the frames to persist. MJB is a compiled, version-specific
  artifact; this feature requires the pinned MuJoCo **3.3.5**.
  [MuJoCo model saving](https://mujoco.readthedocs.io/en/3.3.5/modeling.html#saving-models)
- Regenerate MJB when the robot changes. A successful build without the option
  retires any previous `spirob_aligned.mjb`, preventing stale model reuse.
- This helper supports canonical standalone SpiRob meshes, not robot arrays
  with shared assets, plugins/SDF octrees, textured link geoms, ellipsoid fluid
  interactions or arbitrary mesh placements. Unsupported inputs fail explicitly.
- Body/site consumers keep their convention. Geom-local observations and
  orientation sensors deliberately change; existing policies that use them
  require review. No mjlab or GPU/MJX training equivalence is claimed.
- Floating-point collision/ray computations are not guaranteed bit-identical.
  In particular, exactly axis-parallel rays through zero-width triangle bounds
  can differ at a numerical boundary. The ray regressions use oblique rays and
  compare both mesh and full-scene intersections.

## Verification

Full suite: **219 passed, 1 pre-existing xfailed**, in 70.61 seconds. The expected
failure remains the previously documented F-08 tendon-routing question.

Regression checks cover 2-, 3- and 4-cable generated models, including all
21 links, reference and bent poses, original-model immutability, repeated
alignment, and binary save/reload. They compare actual world vertices/normals,
all body/joint/site/tendon/actuator arrays, cable lengths, and mesh/scene rays.
Nonzero negative tendon controls are used for a 200-step dynamics comparison.
Sphere/box obstacles touching every link exercise contact distances, positions,
normals and a 20-step contact trajectory. Geom-frame alignment is checked from
`MjData.geom_xmat`, so a changed quaternion alone cannot pass the regression.

A four-cable build with aligned MJB was reopened and audited successfully.
Rebuilding without alignment retired that MJB and reproduced the XML and all
21 source STLs byte-for-byte. The two-/three-cable figure above was rendered
with native MuJoCo Geom frames using the same camera before and after alignment;
only display transparency/frame size were adjusted for visibility.

The dev requirements now explicitly include SciPy, which the existing STL
nearest-neighbour regression already imported.

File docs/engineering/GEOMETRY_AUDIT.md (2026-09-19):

> Engineering history. For current commands, parameters and supported workflows, use the [main README](../../README.md).

# SpiRob Geometry Audit

**Scope:** `spirob-physics-model-development-pipeline` (primary), with cross-checks
against `spirob-assembly` and behavioural reference to `Open-Spiral-Robots`.

**Status:** Phase 1 complete. **Phase 2 complete** — see
`docs/CANONICAL_GEOMETRY.md`. Findings below carry their post-Phase-2
disposition. Three Phase 1 findings were revised on further evidence; those
revisions are marked **REVISED** and explained in place. Historical wording is
preserved and struck through rather than deleted, so the original reasoning
stays auditable.

**Phase numbering.** Two numbering schemes appear in this project's history and
they do not line up. The original eleven-part task specification numbered the
canonical geometry model "Phase 3", CAD "Phase 5", the GUI "Phase 8" and so on.
The project as executed uses its own sequence: **Phase 1 = audit**,
**Phase 2 = canonical geometry layer**, with fabrication, GUI and splitter work
still ahead and not yet numbered. Throughout this document, unqualified "Phase
1" and "Phase 2" mean the *project* phases. Where a reference to the original
specification's numbering is intended, it is written as "spec Phase N".

**Audited commits**

| Repository | Commit | Date |
|---|---|---|
| `spirob-physics-model-development-pipeline` | `a6ea28d` | 2026-05-14 |
| `spirob-assembly` | `f95d791` | 2026-05-16 |
| `Open-Spiral-Robots` (reference only) | `a03ef17` | 2026-05-10 |

**Provenance note.** No source was copied from `Open-Spiral-Robots`. That
repository is PolyForm Noncommercial; the primary and assembly repositories are
MIT. It was read for behavioural reference only — specifically the existence and
rough shape of its `fabrication/splitter_generator.py` and `design-tool` feature
set. Every equation in this document is transcribed from the task specification
and from Wang et al. 2024, and every implementation in `tools/` was written
against those equations. A formal `docs/LICENSE_PROVENANCE.md` is still to be
written as part of the final deliverables; until then this note stands.

---

## 0. Length vocabulary

Five quantities are easy to conflate and are kept strictly separate everywhere
in this document and in `spirob/geometry.py`. Two of them are *lengths*; two are
*effects* that relate those lengths; one is a *structural* property.

| Term | Meaning | Field |
|---|---|---|
| **requested continuous length** | what the user asks for in `params.json` as `L`; a spiral **arc** length | `requested_continuous_length_m` |
| **effective continuous length** | the spiral **arc** actually generated, after the terminal-unit policy has been applied | `effective_continuous_length_m` |
| **discrete chord (backbone) length** | the sum of straightened **chords**, i.e. what the built link chain physically measures | `discrete_chord_length_m` |
| **partial-unit completion** | the *effect* `requested -> effective`. Zero under `exact_requested_length`; positive under `whole_units` | `completion_delta_m` / `_rel` |
| **arc-versus-chord shortening** | the *effect* `effective -> discrete`. Always negative, second order in `Delta_theta`, present under **both** policies | `chord_deficit_m` / `_rel` |

```
requested continuous length
    |
    |  partial-unit completion        (unit-structure effect)
    v
effective continuous length
    |
    |  arc-versus-chord shortening    (discretisation effect)
    v
discrete chord (backbone) length
```

The two effects have **different causes and different remedies**. Completion is
about whether the requested length contains a whole number of nominal units, and
is controlled by `terminal_unit_policy`. Arc-versus-chord shortening is about
straightening curved intervals into straight links, and is controlled only by
`Delta_theta`. Selecting `whole_units` does *not* remove the chord deficit — it
slightly increases it, because the model is longer.

The two shipped policies are:

| `terminal_unit_policy` | Behaviour |
|---|---|
| `exact_requested_length` | **Default.** Effective length equals requested length exactly. Permits one partial unit, which after inversion is the base link. |
| `whole_units` | Extends the spiral to the next complete nominal unit boundary. Never shortens. No partial unit. Reports the excess. |

Earlier drafts of this document floated a `length_definition` parameter with
values `continuous_arc` / `discrete_backbone`, and a `terminal_unit_policy` with
values `truncate` / `uniform_dtheta` / `uniform_scale`. **None of those shipped.**
Where they still appear below they are marked as superseded. Note separately that
`tools/geometry_audit.py` retains an internal, independent reference
implementation whose own helper argument is still spelled `truncate`; that is a
test-oracle detail, not a user-facing policy name, and is deliberately not
renamed so the oracle stays a genuine cross-check.

---

## 1. Reference equation set

With `E = exp(2*pi*b)`:

| Quantity | Equation |
|---|---|
| Full included taper angle | `phi(b) = 2*atan( b*(E-1) / (sqrt(1+b^2)*(E+1)) )` |
| Tip width relation | `a = d_tip/(E-1)` |
| Central spiral | `r_c(theta) = 0.5*a*(E+1)*exp(b*theta)` |
| Local width | `d(theta) = a*(E-1)*exp(b*theta)` |
| Continuous length | `L_arc(q) = sqrt(1+b^2)/b * 0.5*a*(E+1) * (exp(b*q)-1)` |
| Adjacent-unit scale | `beta = exp(b*Delta_theta)` |
| Root width | `d_root = d_tip*exp(b*q0)` |

These are implemented independently in `tools/geometry_audit.py` so that
agreement with `helper_functions.py` is a genuine cross-check rather than a
tautology.

### 1.1 Verification against the committed defaults

`params.json` at `a6ea28d`: `L = 0.22628`, `d_tip = 0.007139`,
`phi_deg = 6.3`, `Delta_theta_deg = 30.78`, `n_cables = 3`.

| Quantity | Specification | Computed | Agreement |
|---|---|---|---|
| `b` | 0.1369640839 | 0.1369640839 | exact to 10 s.f. |
| `a` | 0.0052319156 m | 0.0052319156 m | exact to 10 s.f. |
| `q0` | 10.9632013369 rad | 10.9632013369 rad | exact to 10 s.f. |
| `d_root` | 0.0320448838 m | 0.0320448838 m | exact to 10 s.f. |
| `beta` | 1.076353346 | 1.076353346 | exact to 10 s.f. |

**Tolerances used in `tests/test_analytical.py`:**

| Constant | Value | Applies to |
|---|---|---|
| `REL_TIGHT` | `1e-9` | closed-form identities (round trips, quadrature) |
| `REL_REF` | `5e-9` | the five reference constants above, quoted to 10 s.f. |
| `ABS_GEOM` | `1e-12` | metre-scale geometric identities |

The reference constants live only in the test module. Production code derives
them; nothing hard-codes them.

### 1.2 Implementation agreement

`helper_functions.generate_spiral_pose()` computes

```python
A  = (a/b)*sqrt(b**2 + 1)*(e2pb + 1)/2
Q0 = (1/b)*log(1 + Length/A)
r1 = (a/2)*(exp(2*pi*b) + 1)*exp(b*theta)     # side_A, the central spiral
r2 = a*exp(b*theta)                            # side_B, the inner edge
```

All four agree with the reference set. `A` is exactly the bracketed prefactor of
`L_arc`, so `Q0` is its exact closed-form inverse. `r1` is `r_c`. `r2` is
`r_c - d/2`, since

```
r_c - d/2 = 0.5*a*exp(b*theta)*[(E+1) - (E-1)] = a*exp(b*theta)
```

and the corresponding outer edge `r_c + d/2 = a*exp(b*(theta + 2*pi))` — the
self-similarity property that makes the design tile. Confirmed by
`test_outer_edge_is_inner_edge_one_turn_later`.

`solve_b_for_phi()` agrees with an independent bisection to `1e-8` relative over
`phi_deg` in [1, 40]. Two robustness notes, neither currently triggered:

- The fallback `return max(1e-6, tan(phi_target/2))` on bracketing failure
  silently returns a *different, wrong* `b` rather than raising. It is
  unreachable for `phi_deg` in the validated range `(0, 45)`, but it is a
  latent silent-failure path.
- `atan2(num, den)` is used where `2*atan(num/den)` is specified. Identical for
  `b > 0` because `den > 0`; harmless, but it obscures the intent.

**Verdict: the analytical core is correct.** Every discrepancy found in this
audit is in documentation, discretization semantics, or downstream consumers.

---

## 2. Findings

Severity: **A** = wrong output today · **B** = wrong documentation or a
correctness trap · **C** = maintainability risk.

| ID | Sev | Summary |
|---|---|---|
| F-01 | B | `phi_deg` is documented as a half-angle. It is the full included angle. |
| F-02 | B | `README.md` quick start uses `python build.py --nlobe`; `build.py` has no such flag. |
| F-03 | A — **reported, by design** | Requested `L` is a continuous arc length; the built model realises a chord sum 1.16 % shorter. Now measured and reported separately as arc-versus-chord shortening. |
| F-04 | ~~A~~ → **not a defect** | **REVISED.** `Invert_pose()` anchors the TIP at the requested length. Intentional frame convention. |
| F-05 | ~~B~~ → **not a defect** | **REVISED.** The partial unit becomes `link_001` by design, preserving large-at-base ordering. |
| F-06 | B | Straightened elements have exactly zero intra-element taper. Undocumented, and downstream code assumes otherwise. |
| F-07 | A — **FIXED** | `preview.py` and `csv2xml.py` disagreed about the tendon path by up to 1.2956 mm — 86 % of `tendon_inward_shift`. Now agree to 1.1e-15 m. |
| F-08 | B — **deferred by decision** | The `-dz*tan(phi/2)` tendon correction applies a taper the discretised geometry does not have. |
| F-09 | B | Realised tip/root widths differ from `d_tip`/`d_root` by −0.92 % / −2.99 %. |
| F-10 | C — **FIXED** | `preview.py` carried a full private fork of the spiral maths. Deleted in Phase 2. |
| F-11 | C | `csv2xml.py` defaults `--phi-deg` to 5.7 while `params.json` ships 6.3. |
| F-12 | C | Three modules use three mutually inconsistent vertex-naming conventions. |
| F-13 | C | `requirements.txt` pins CadQuery to a git SHA; PyPI now ships a working 2.8.0. |

---

### F-01 · `phi_deg` is the full included taper angle — B

`README.md` describes `phi_deg` as *"Taper half-angle of the logarithmic
spiral"*. This is wrong. The code is right; only the documentation is wrong.

Proof. The half-width is `h(theta) = d(theta)/2`, and arc length satisfies
`ds/dtheta = sqrt(1+b^2)*r_c`. Therefore

```
dh/ds = [0.5*a*(E-1)*b*exp(b*t)] / [0.5*a*(E+1)*exp(b*t)*sqrt(1+b^2)]
      = b*(E-1) / ((E+1)*sqrt(1+b^2))
      = tan(phi/2)
```

So `tan(phi/2)` — not `tan(phi)` — is the half-width slope, which is exactly the
definition of `phi` as the **full included** angle between the two boundary
edges. Both consumers already use `phi/2` correctly:

- `csv2xml.py:183` — `HALF_PHI = math.radians(config.phi_deg / 2)`
- `csv2geom_nlobe.py:241` — `draft_angle_deg = phi_deg / 2.0`

Locked by `test_phi_is_the_full_included_angle`, which fails by a factor of two
if the semantics are ever flipped.

**Action.** Correct the README wording. Keep the parameter name. Accept
`taper_angle_deg` as an alias with an explicit conflict check that errors if
both keys are present with different values.

---

### F-02 · Documented quick-start command fails — B

`README.md` instructs:

```bash
python build.py --nlobe
```

`build.py` defines only `--params`, `--noclean`, `--no-preview`, `--plain`,
`--safe`, `--fast`, `--high`. `argparse` exits 2 on the unknown flag. `--nlobe`
exists on `preview.py`, not `build.py`; in `build.py` n-lobe is implicit
(`use_nlobe = (not args.plain) and (n_cables >= 3)`).

**Action.** Add `--nlobe` as an accepted no-op alias for backward compatibility
with any user scripts, and fix the README.

---

### F-03 · Arc-versus-chord shortening — A, now measured and reported

`q0` is solved so the *continuous arc* length equals `L`. The pipeline then
straightens each sampled interval as a **chord**. Chords are shorter than arcs,
so the built chain measures less than the requested arc:

| Quantity | Value |
|---|---|
| Requested continuous length | 226.2800 mm |
| Effective continuous length | 226.2800 mm |
| Discrete chord (backbone) length | **223.6554 mm** |
| Arc-versus-chord shortening | −2.6246 mm |
| Relative | **−1.1599 %** |

This matches the specification's expected 223.6554 mm exactly. The effect is
second order in `Delta_theta`; `test_discrete_converges_to_continuous` confirms
`O(Delta_theta^2)` convergence across 0.5°–60°.

**This is a discretisation effect, not a unit-completion effect.** Under the
default policy the effective length equals the requested length exactly, so the
completion delta is zero while this deficit is −2.6246 mm. The two are reported
as separate fields and must not be summed into a single "error". See §0.

**Disposition (Phase 2): reported, not silently absorbed.** The superseded
proposal was a `length_definition` parameter with values
`continuous_arc` / `discrete_backbone` that would have re-solved `q0` so the
*chord sum* hit `L`. That did not ship, and deliberately so: it would change the
spiral for every existing `params.json`. What shipped instead is measurement —
`LengthReport` carries all three lengths and both effects, `to_manifest()`
serialises them, and `tools/geometry_audit.py` prints them. A user who wants a
226.28 mm backbone can now see exactly what they are getting and by how much it
differs.

The chord-solving routine still exists in `tools/geometry_audit.py` as
`solve_q0_for_discrete_length()` (deterministic bracketed bisection, explicit
`tol` and `max_iter`, raises on failure to bracket or converge) and remains
covered by `tests/test_analytical.py`. It is retained as a verified reference
implementation should a future major version choose to adopt it; it is not
reachable from the shipped pipeline. Measured: it drives the relative error
below `1e-10`, raising `q0` from 10.9632 to a value whose continuous arc length
is 228.9254 mm.

---

### F-04 · Tip anchoring at the requested length — REVISED: not a defect

**Phase 1 claimed this was a severity-A defect. That was wrong, and the
correction is recorded here rather than quietly deleted.**

```python
def Invert_pose(quads, Length):
    q[:, 1] = -q[:, 1] + Length      # Length is the REQUESTED L
```

Phase 1 read the resulting `z_min = 0.0026246` as the base failing to sit at
the origin. Tracing the pipeline shows the opposite reading is the right one:
the reflection anchors the **tip** at exactly `y = L`, and the base then
necessarily sits at `L - L_discrete`. Verified to `1e-12`:

```
inverted span y = 0.0026246 .. 0.2262800
TIP  y = 0.2262800 == requested L      -> anchored exactly
BASE y = 0.0026246 == L - L_discrete
```

**The 2.6246 mm is the continuous-arc versus discrete-chord difference** — the
same quantity reported by F-03 as arc-versus-chord shortening, appearing here in
the frame because the tip is the anchored end. It is **not** an accidental
MuJoCo root displacement, and the geometry must **not** be shifted by it.

Two further facts settle it:

1. **The offset never reaches the simulation.** `csv2xml.py:313` overrides
   `rel[0]` from `post_gen.robot_pos`, discarding the CSV-frame root position
   entirely. Confirmed against the built model: `link_001` world position is
   exactly `[0, 0, 0.22628]`.
2. **The default `post_gen` block is consistent with tip anchoring.**
   `robot_pos = [0, 0, 0.22628]` with `robot_quat = [0, 0, -1, 0]` (180° about
   Y) hangs the robot from `z = L` so the tip descends to `z ≈ 0`. The
   2.6246 mm is the resulting tip-to-floor clearance, not a stray offset.

**Disposition.** Documented as a frame convention in `spirob/geometry.py` and
exposed as `BaseFrame.origin_offset_m` so a future CAD exporter can consume it
explicitly. The Phase 1 xfail `test_base_of_robot_sits_at_origin` was replaced
by `test_inversion_anchors_the_tip_at_the_requested_length`, which asserts the
correct convention — a stronger assertion, not a weakened one.

---

### F-05 · The partial unit is the base link — REVISED: correct by design

**Phase 1 flagged this as surprising and implicitly wrong. It is neither.**

`theta[i] = min(i*Delta_theta, q0)` clips the last spiral interval at `q0`, and
`Invert_pose()` then reverses the chain, so the partial unit becomes
`link_001`. With the committed defaults, `q0/Delta_theta = 20.4076`, so unit 21
spans 12.5452° instead of 30.78°. (This clipping is the *mechanism*. It is not a
policy name: the shipped policy that permits it is `exact_requested_length`.)

**The requested length creates a partial terminal unit. After
`Invert_pose()`, this unit becomes the base link by design, preserving the
intended large-at-base and small-at-tip ordering.**

The spiral is generated tip-first: `theta = 0` is the smallest radius. The
clipped interval therefore lands on the largest-radius end, which after
inversion is the base. The smallest element remains at the tip. Moving the
partial unit to the tip would invert the size ordering the whole design depends
on. **This is not an inversion or ordering defect and must not be "fixed".**

Confirmed numerically: `link_001` is simultaneously the partial unit
(12.5452° span) *and* the largest unit (31.0876 mm realized width). It is
partial in **angular span** while remaining at the **large-radius, wide end**.
`link_021` is the smallest unit, at the tip, and is complete.

**Remaining fabrication note, not a geometry defect.** A printed robot built
from the default parameters will have a partial unit at its base. If a whole
number of units is wanted, select the Phase 2 policy:

```json
"terminal_unit_policy": "whole_units"
```

which extends the spiral to the next complete boundary and reports the excess
length. It never shortens.

### F-06 · Straightened elements have exactly zero intra-element taper — B

This is a *property of the model* that no module documents and at least one
module contradicts.

Because the inner edge is a constant radial scaling of the centreline —
`B(theta) = k * A(theta)` with `k = 2/(E+1)`, independent of `theta` — the
straightening step maps both inner-edge endpoints to the **same** lateral
offset:

```
x(B1 - A0) = k*x(R*A1) - x(R*A0) = (k-1)*x(R*A0) = x(B0 - A0)
```

using `x(R*A1) = x(R*A0)`, which holds because `R` rotates `A1 - A0` onto `+Y`.

Measured: `max |B0x − B1x| = 3.47e-18 m` across all 21 elements — machine zero.

So each straightened element is a **constant-width block with two slanted end
faces**. The taper is a 21-step staircase between elements, not a continuous
loft. The revolved solid is a cylinder with conical end caps, and the wedge
between caps is what provides bending clearance. This is a legitimate
discretisation — but it means:

- the realised width of unit `i` is `d(theta_i) * dist(O, chord_i) / r_c(theta_i)`
  (proved to `1e-17` by the audit tool), **not** `d(theta_i)`;
- any downstream code that assumes an intra-element taper is compensating for
  something that is not there. See F-08.

---

### F-07 · Preview and MJCF disagree about the tendon path — A

`preview.py:122` claims:

> *"The inward shift and taper correction from csv2xml are replicated here so
> the preview matches what the XML will actually use."*

It does not. The two modules unpack the **same array** with **different names**:

| Module | Unpacking | Meaning of slot 2 / slot 3 |
|---|---|---|
| `helper_functions.generate_cable_sites_csv_zrot_from_P` | `A0, A1, B1, B0 = quad` | `B1` = slot 2, `B0` = slot 3 |
| `preview._tendon_path` | `A1, A0, B0, B1 = quad` | `B0` = slot 2, `B1` = slot 3 |

`B0` and `B1` are therefore **swapped** between the producer and the preview.
Consequences:

- `preview` computes `dz = B1[1] - B0[1]`, which has the **opposite sign** to
  `csv2xml`'s `dz = s2_local[2] - s1_local[2]`;
- the taper correction is anchored at the opposite end of every link;
- the two per-link points are emitted in reversed `z` order.

Measured, cable 0, worst case:

```
k    MJCF r(mm)   z(mm)   |  PREVIEW r(mm)  z(mm)   |   dr(mm)
38     12.1653   29.0555  |     13.4609   17.2841   |  -1.2956
```

**Worst radial disagreement: 1.2956 mm**, against a `tendon_inward_shift` of
1.5 mm — an 86 % error in the quantity the preview exists to let you check. The
README explicitly tells users to trust it:

> *"The preview shows the corrected tendon path; verify visually before
> generating STL."*

The MJCF path is the self-consistent one (monotonic in both radius and height,
verified). **The preview is wrong.**

Guarded by strict-xfail `test_preview_tendon_path_matches_mjcf`, with
`test_preview_mjcf_disagreement_is_the_documented_magnitude` pinning the
1.2956 mm figure so a partial fix cannot slip through.

**This is a naming defect that produced a real numerical error in one consumer.**
The intended geometry was established numerically first: the MJCF path was
independently checked for monotonicity and containment before being declared
the reference.

**FIXED in Phase 2.** `preview.py` no longer computes tendon geometry. It reads
`SpiRobGeometry.tendon_path(0)`, the single canonical definition, which the
test suite proves equals `csv2xml`'s independent computation. Measured after
the change: worst radial disagreement **1.102e-15 m**, worst height
disagreement **1.804e-15 m** (down from 1.2956e-3 m). Guarded by
`test_preview_mjcf_agreement_is_at_float_precision`.

---

### F-08 · The tendon taper correction models a taper that is not there — B

```python
r2_new = max(r1_old - TENDON_INWARD_SHIFT - dz*math.tan(HALF_PHI), 1e-6)
```

Per F-06 the link's outer radius is *constant* along its length
(`max |r1_old − r2_old| = 3.5e-18 m`). Subtracting `dz*tan(phi/2)` within the
link therefore pulls the second site inboard of a surface that never moved, and
the next link's `s1` re-anchors at its own `r_old − shift`. The routed tendon is
a sawtooth rather than a constant offset from the surface:

| Link | intra-link taper applied | jump at boundary into next link |
|---|---|---|
| 1 → 2 | 0.2808 mm | −0.9499 mm |
| 11 → 12 | 0.3341 mm | −0.1895 mm |
| 20 → 21 | 0.1723 mm | −0.0977 mm |

The path stays monotonic, and the per-link error is bounded (0.16–0.65 mm), so
this is not catastrophic — but at the tip the tendon sits at 1.8766 mm radius
where a constant-offset rule gives 2.0366 mm. That 0.16 mm is 11 % of the shift,
and it will not agree with a CAD channel generated from the same nominal rule.

**Disposition: DEFERRED BY DECISION, and the deferral is now safe.**

Phase 2 reproduces this behaviour deliberately and exactly. Changing the
routing rule would change existing MJCF output, which Phase 2 explicitly
forbids. What Phase 2 *does* change is that there is now exactly one place to
make the change: `spirob.geometry._build_tendon_paths`. Before, the rule was
implemented twice (in `csv2xml.py` and, differently, in `preview.py`).

The open question is unchanged: should the routed tendon be a constant offset
from the realised staircase surface, or a smooth taper fitted through the
links? That decision belongs with the fabrication phase, because it must be
made once for both the MJCF tendon and the printed channel. Held as the single
remaining strict xfail, `test_tendon_offset_from_surface_is_constant`.

---

### F-09 · Realised tip and root widths miss their targets — B

| | Nominal | Realised | Error |
|---|---|---|---|
| Tip width | 7.1390 mm | 7.0733 mm | −0.92 % |
| Root width | 32.0449 mm | 31.0876 mm | −2.99 % |

A consequence of F-06: the realised width is scaled by the chord-to-radius
sagitta factor `dist(O, chord_i)/r_c(theta_i)`, which is < 1 and shrinks as the
unit's angular span grows.

The root figure above is policy-dependent, which is worth stating precisely.
Under `exact_requested_length` the base unit spans only 12.5452°, so its sagitta
factor is 0.99966 and its realised width (31.0876 mm) is close to the nominal
width at its own start angle. Under `whole_units` the base unit spans the full
30.78°, the factor drops to 0.990794, and the realised root width *falls* to
30.8119 mm even though the spiral now extends further and the nominal root width
*rises* to 33.4726 mm. Fabrication must therefore read
`realized_root_width_m`; `nominal_root_width_m` is the width the continuous
spiral reaches at `q0`, which no straightened block ever realises.

A user asking for a 7.139 mm tip gets 7.073 mm. Harmless in simulation;
material for fabrication fit. Phase 6 validation must report both nominal and
realised widths, which the manifest already does.

---

### F-10 · `preview.py` forks the spiral maths — C

`preview.py` privately reimplements `_phi_from_b`, `_solve_b`, `_normalize`,
`_angle_between`, `_rotate2d`, and the whole spiral → straighten → invert
pipeline as `_build_quads`, rather than importing `helper_functions`.

The fork has already drifted and been re-synced by hand — three lines carry the
comment `# Correction made on Mar 19, 26`, mirroring a fix applied separately to
`helper_functions.py`. F-07 is the fork drifting again and not being caught.

This was the strongest argument for the canonical model.

**FIXED in Phase 2.** The fork is deleted. `_phi_from_b`, `_solve_b`,
`_normalize`, `_angle_between`, `_rotate2d` and the private `_build_quads`
pipeline are gone from `preview.py`; it now imports `spirob.geometry`. A
regression guard, `test_preview_no_longer_forks_the_spiral_maths`, fails if any
of those definitions reappears. `csv2geom_nlobe.py` and `csv2xml.py` are the
remaining consumers to migrate; both are unchanged in Phase 2 so that default
output stays byte-identical.

---

### F-11 · `--phi-deg` default mismatch — C

`csv2xml.py` defaults `--phi-deg` to `5.7`; `params.json` ships `6.3`.
`build.py` always passes it explicitly, so the pipeline is fine — but anyone
invoking `csv2xml.py` directly (as the README's project-structure section
implies is possible) silently gets a different taper. Same for
`csv2geom_nlobe.py:231`, `phi_deg=5.7`. Defaults should be `None` and required
from params.

---

### F-12 · Three vertex-naming conventions — C

| Module | Convention | Slot 0 |
|---|---|---|
| `helper_functions` (pre-invert) | `[A0, A1, B1, B0]` | centre at `theta_i` |
| `helper_functions.generate_cable_sites_csv_zrot_from_P` | `A0, A1, B1, B0` | bottom centre |
| `preview.py`, `csv2geom_nlobe.py` | `A1, A0, B0, B1` | bottom centre |

Both post-invert conventions pick the *same points*; they disagree only on
labels. That is survivable in the STL path (which only ever reads `x`/`z` of
each slot) and fatal in the tendon path (F-07), which uses a signed `dz`.

Worse, `generate_cable_sites_csv_zrot_from_P`'s own docstring contradicts its
own code: it documents `P[i] = [A1_i, A0_i, B0_i, B1_i]` and
`site1: (B1x*cosψ, B1x*sinψ, B0y)` — mixing the `x` of one vertex with the `y`
of another — while the code correctly pairs `r0` with `B0y`.

**Action.** Future consumer-migration work: replace all tuple unpacking with a frozen dataclass
carrying explicit `centerline_start` / `centerline_end` /
`inner_start` / `inner_end` fields. No positional unpacking anywhere.

---

### F-13 · CadQuery pinning — C

`requirements.txt` pins `cadquery @ git+https://github.com/CadQuery/cadquery.git@d338160`
plus `cadquery-ocp==7.8.1.1.post1`. A clean `pip install cadquery` now resolves
to **cadquery 2.8.0 / cadquery-ocp 7.9.3.1.1** from PyPI and works, which
materially simplifies Phase 5/6/10 CI. Verified in this audit environment; the
full CSV → 21 STL → MJCF pipeline ran green on it.

---

## 3. Instrumentation as shipped

`tools/geometry_audit.py` now has two clearly separated halves.

**Upper half — the reference oracle.** An independent transcription of the
published equations, importing nothing from the production path. It is retained
precisely so the test suite can check `spirob/geometry.py` against something
that was not derived from it. Its internal helpers still use the exploratory
vocabulary (`theta_samples(..., "truncate")`, `solve_q0_for_discrete_length`,
`discrete_backbone_length`). Those are oracle-internal argument names, **not**
user-facing policy values, and are intentionally left alone.

**Lower half — reporting.** Consumes the canonical model and performs no
geometry of its own. The Phase 1 statement that this file "is read-only and
imports nothing from the production path" is therefore **superseded**: the
reporting half imports `spirob.geometry`.

Reported per build, via `SpiRobGeometry.to_manifest()`:

```
requested continuous length · effective continuous length
discrete chord (backbone) length
partial-unit completion delta (absolute and relative)
arc-versus-chord shortening (absolute and relative)
requested Delta_theta · effective/actual per-unit angular spans
units total · complete units · partial unit present · partial unit span
effective q0 · nominal beta · per-unit scale ratios
nominal and realized tip width · nominal and realized root width
full taper angle · base-frame anchor · per-unit slit references
```

emitted as a versioned JSON build manifest (`--out`, `schema_version` 2.0).
Discrete chord length is defined exactly as specified:

```
sum( norm( center_point(theta[i+1]) - center_point(theta[i]) ) )
```

Both shipped `terminal_unit_policy` values — `exact_requested_length` and
`whole_units` — are exercised by the test suite, and
`--compare-policies` prints them side by side. The exploratory
`length_definition` parameter and the `uniform_dtheta` / `uniform_scale`
policies were **not** implemented and are not planned; see §0.

---

## 4. Baseline regression state

Established before any change, on the audit commits:

| Suite | Result |
|---|---|
| `spirob-assembly/test_pipeline.py` | **17 passed, 0 failed** |
| Primary: `spirob_csv_generator.py` | 21 elements, CSV written |
| Primary: `csv2geom_nlobe.py` | 21/21 STL written (CadQuery 2.8.0) |
| Primary: `csv2xml.py` | XML written |
| MJCF load (MuJoCo 3.10.0) | `nbody=22 njnt=21 nsite=128 ntendon=3 nu=3 nmesh=21` |
| MJCF 200-step rollout | no NaN; total mass 40.329 g; tendon rest length 219.66 mm |
| New `tests/` (Phase 1) | **55 passed, 3 xfailed** |
| New `tests/` (Phase 2) | **139 passed, 1 xfailed** |

Phase 1 held three strict xfails. Their Phase 2 disposition:

| Phase 1 xfail | Disposition |
|---|---|
| F-04 `test_base_of_robot_sits_at_origin` | **Wrong expectation.** Replaced by `test_inversion_anchors_the_tip_at_the_requested_length`, which asserts the real convention. |
| F-07 `test_preview_tendon_path_matches_mjcf` | **Real defect, fixed.** Marker removed; the test now passes on merit. |
| F-08 `test_tendon_offset_from_surface_is_constant` | **Deferred by decision.** Still strict-xfail, with the reason restated. |

Default pipeline output is byte-identical to `40fb850`: CSV, XML and all 21
STL files compare equal.

---

## 5. Change surface — status

This section was written in Phase 1 as a forward plan. It is now annotated with
what actually landed. Rows marked **landed** are complete on
`canonical-geometry`; the rest remain future work.

### 5.1 New files

```
docs/GEOMETRY_AUDIT.md          landed  (this document)
docs/CANONICAL_GEOMETRY.md      landed  (Phase 2)
spirob/__init__.py              landed  (Phase 2)
spirob/geometry.py              landed  (Phase 2) — SpiRobGeometry canonical model
tools/geometry_audit.py         landed  (Phase 1, rewired in Phase 2)
tests/test_analytical.py        landed  (Phase 1)
tests/test_conventions.py       landed  (Phase 1, revised in Phase 2)
tests/test_canonical_geometry.py landed (Phase 2)

docs/FABRICATION_PIPELINE.md    future  (fabrication phase)
docs/PARAMETER_REFERENCE.md     future
docs/LICENSE_PROVENANCE.md      future
docs/MIGRATION_NOTES.md         future
fabrication/                    future  — CAD exporter + validator + splitter
gui/                            future  — lazy-imported
```

The Phase 1 plan listed the canonical model as "Phase 3" and a separate
`spirob/tendons.py`. Both are superseded: the model landed as project Phase 2,
and the canonical tendon definition lives in
`spirob.geometry._build_tendon_paths` rather than a separate module, so there is
one file to read and one place to change the routing rule when F-08 is settled.

### 5.2 Modified files

| File | Change | Status / Risk |
|---|---|---|
| `preview.py` | delete the private fork, import canonical model, fix F-07 | **landed** — visual output only; no pipeline artefact changed |
| `params.json` | add `terminal_unit_policy` | **landed** — key is optional and defaults to current behaviour |
| `helper_functions.py` | keep every public signature; re-express bodies over `SpiRobGeometry` | not started. **Medium** — `spirob-assembly` does not import it, but user notebooks may |
| `spirob_csv_generator.py` | build geometry via the canonical model; identical CSV bytes under defaults | not started. **High** — the CSV is the pipeline's stable interface |
| `csv2xml.py` | consume canonical tendon paths; `--phi-deg` default `None` | not started. **High** — MJCF is consumed by `spirob-assembly` |
| `csv2geom_nlobe.py` | consume canonical model; STL output unchanged | not started. Medium |
| `build.py` | accept `--nlobe` no-op; emit build manifest | not started. Low |
| `README.md` | fix F-01, F-02 | not started. None |

The superseded `length_definition` key is not in the shipped `params.json` and
is not planned; a `fabrication` block belongs to the fabrication phase.

### 5.3 Backward-compatibility risks

1. **CSV schema is load-bearing.** `csv2geom_nlobe.py`, `csv2xml.py` and
   `spirob-assembly` all parse it by column name. Column names and order must
   not change. Any new field appends only.
2. **Byte-identical default output.** ~~With `length_definition = "continuous_arc"`
   and `terminal_unit_policy = "truncate"`~~ — superseded naming. The
   requirement, restated: with `terminal_unit_policy = "exact_requested_length"`
   (the default, and the behaviour when the key is absent), the refactor must
   reproduce the baseline CSV, STL set and XML exactly. **Verified for Phase 2**
   by building `main` in a separate worktree and comparing: CSV identical, XML
   identical, 21/21 STL identical. The same check must be repeated for each
   remaining consumer migration.
3. ~~**F-04 and F-07 fixes change output.**~~ **CORRECTED — this risk was
   misdiagnosed and does not exist.**

   The Phase 1 text claimed both findings were defects whose repair would break
   byte-identity, and specifically that "the base offset shifts every `z` by
   2.6246 mm". Both halves are wrong.

   - **F-04 is not a defect and nothing is shifted.** `Invert_pose()`
     intentionally anchors the **tip** at the requested length. The 2.6246 mm is
     the continuous-arc versus discrete-chord difference (F-03) surfacing in the
     frame — not an accidental root displacement, and not a quantity to correct
     away. The simulated root pose is established by `csv2xml.py` from
     `post_gen.robot_pos`, independently of this frame offset. No geometry shift
     is required or permitted.
   - **F-07 was a real defect, and fixing it changed no pipeline artefact.** The
     bug lived only in `preview.py`, which produces a PNG and nothing else. CSV,
     STL and XML were never affected, and are byte-identical after the fix.

   The residual risk in this item therefore reduces to F-08, which is
   deliberately unfixed precisely because settling it *would* change MJCF
   output. See item 3a.

3a. **F-08 will change MJCF output when it is settled.** The tendon routing rule
   is still undecided. Whichever rule is chosen, adopting it will move tendon
   site positions and therefore change `spirob_physics_model.xml`. That change
   must ship in its own commit group with the numeric delta published, and must
   be coordinated with the fabrication phase so the MJCF tendon and the printed
   channel agree.
4. **`spirob-assembly` mount alignment.** `test_palm_camera_position` asserts
   `palm_cam Z ≈ L = 0.22628`. If the primary generator starts reporting a
   realised length of 223.6554 mm, that assertion is the first thing to break.
   The manifest must expose both lengths so the assembly layer can choose, and
   the assembly repo must keep its current default.
5. ~~**`post_gen.robot_pos` ... users have compensated for F-04 by hand.**~~
   **CORRECTED.** `post_gen.robot_pos = [0, 0, 0.22628]` is not a hand-applied
   workaround for a defect. It is how `csv2xml.py` establishes the simulated
   root pose: `rel[0]` is overridden from `post_gen`, so the CSV-frame base
   offset never reaches the model. Verified on the built model — `link_001`
   world position is exactly `[0, 0, 0.22628]`. Nothing here needs "fixing" and
   no existing scene moves.
6. **`phi_deg` alias.** Accepting `taper_angle_deg` must error, not warn, if both
   are present and disagree.
7. **CadQuery version.** Moving off the git pin changes the tessellator; STL
   byte-identity across versions is not guaranteed even when the solid is.
   Golden tests must compare geometry (volume, bbox, manifoldness), not bytes.
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

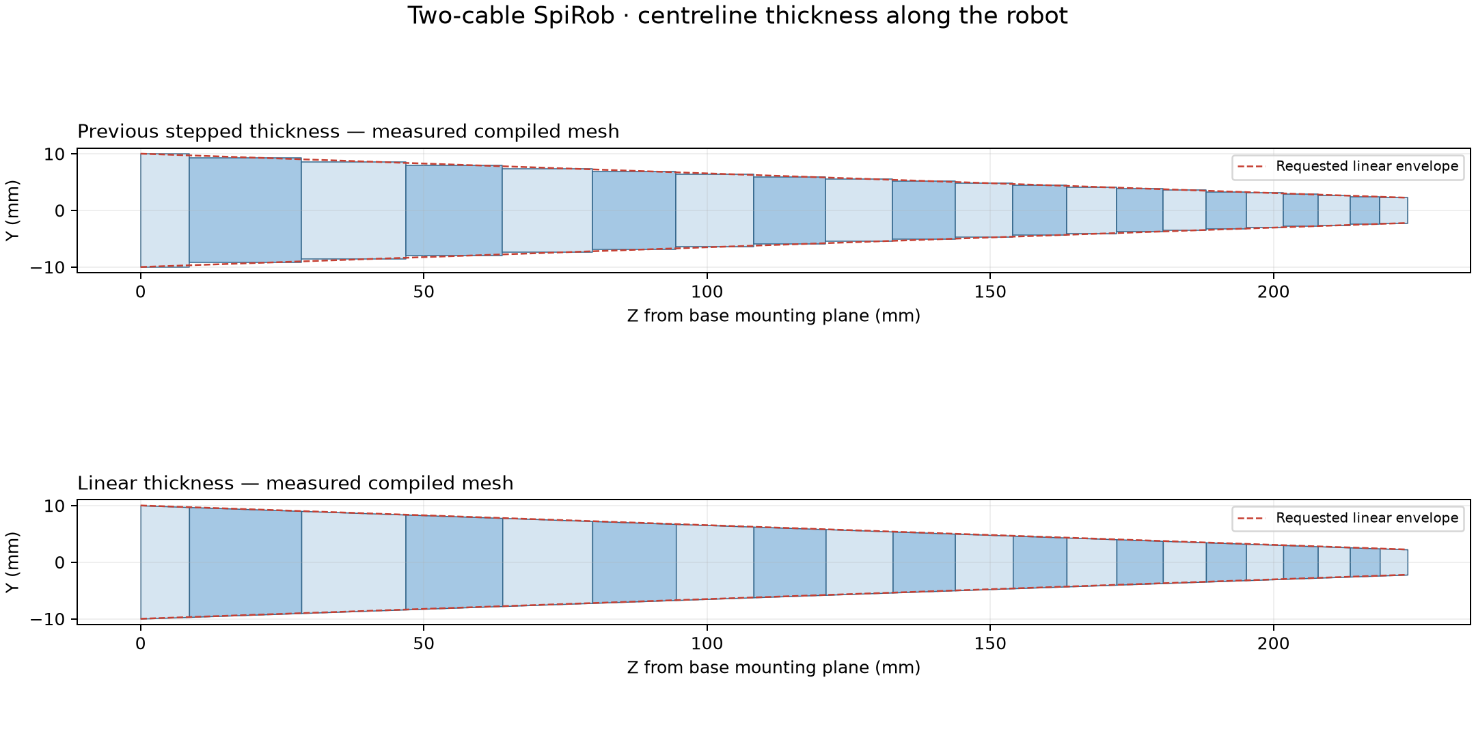
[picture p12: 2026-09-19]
docs/figures/linear-thickness-before-after.png

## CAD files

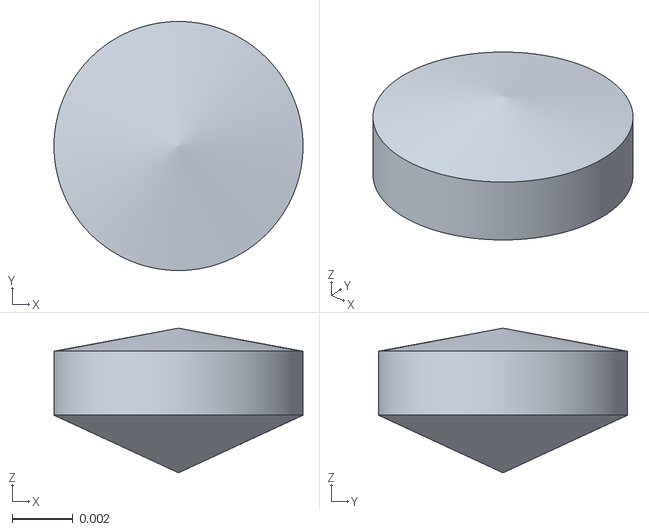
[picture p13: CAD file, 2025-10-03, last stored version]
meshes/link_019.stl
0.00817 x 0.00817 x 0.00475

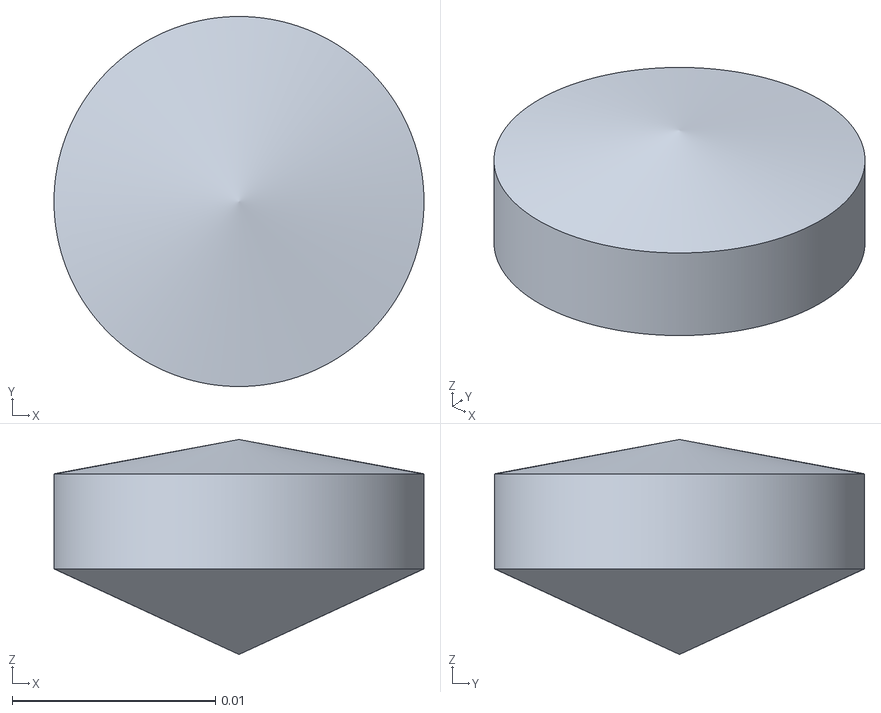
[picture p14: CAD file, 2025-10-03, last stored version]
meshes/link_009.stl
0.0182 x 0.0182 x 0.0106

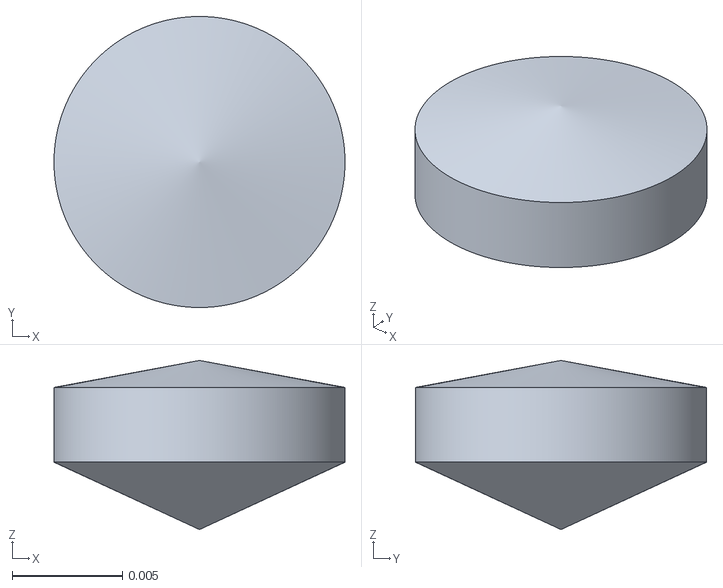
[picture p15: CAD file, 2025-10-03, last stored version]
meshes/link_013.stl
0.0132 x 0.0132 x 0.00767

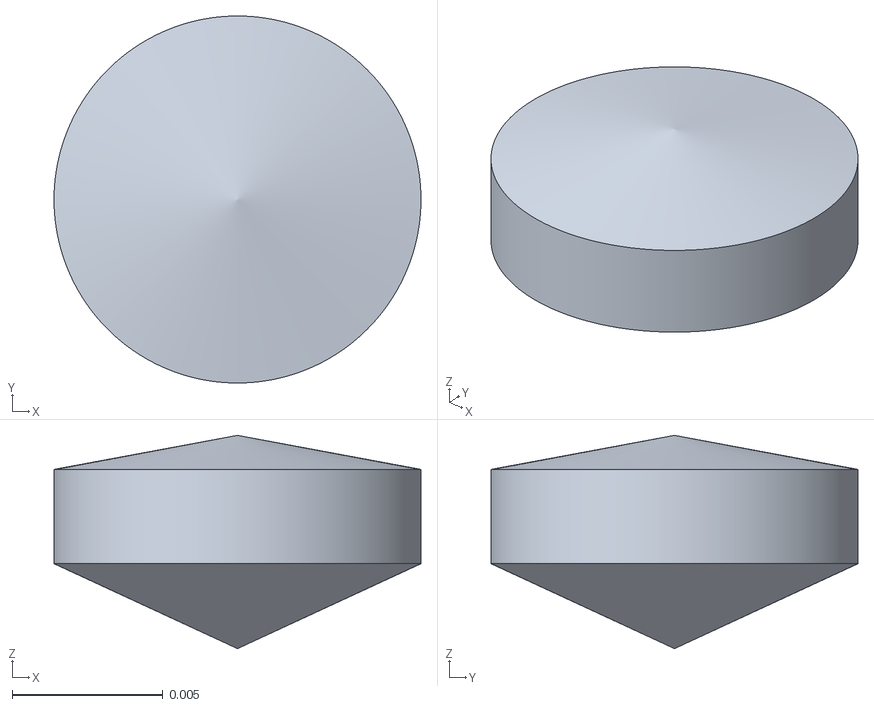
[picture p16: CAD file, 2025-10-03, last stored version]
meshes/link_014.stl
0.0122 x 0.0122 x 0.00708

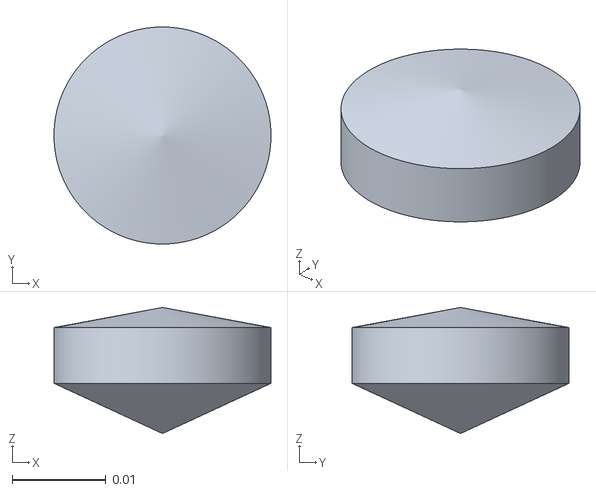
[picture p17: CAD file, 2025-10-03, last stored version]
meshes/link_006.stl
0.0231 x 0.0231 x 0.0134

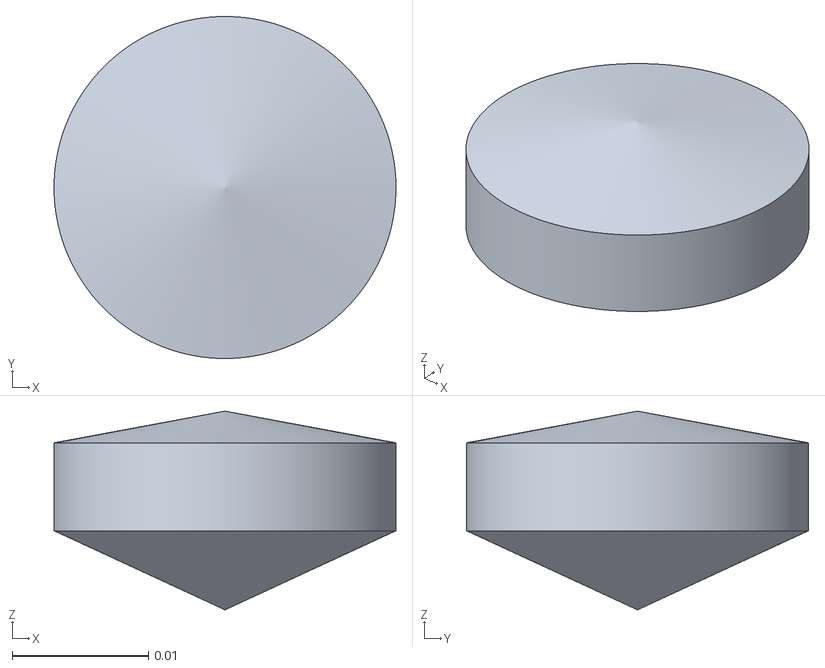
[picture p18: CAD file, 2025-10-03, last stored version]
meshes/link_005.stl
0.0251 x 0.0251 x 0.0146

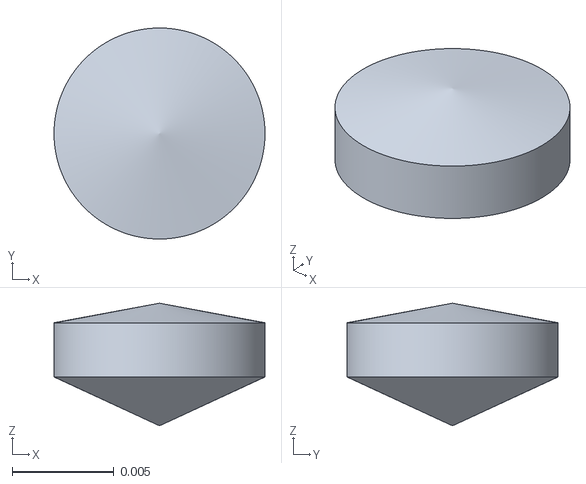
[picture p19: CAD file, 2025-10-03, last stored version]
meshes/link_016.stl
0.0104 x 0.0104 x 0.00604

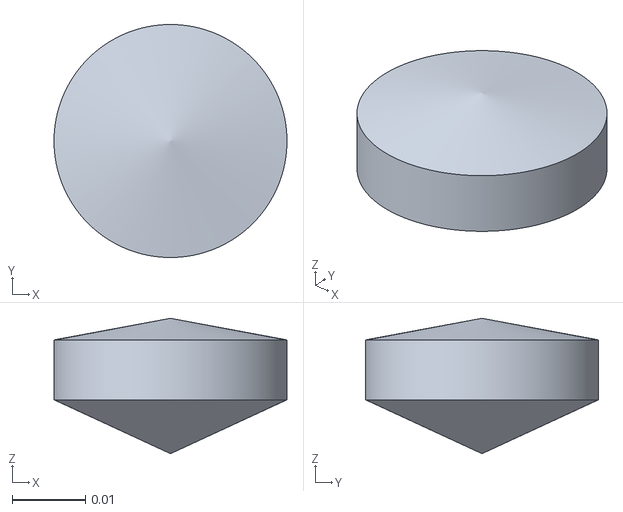
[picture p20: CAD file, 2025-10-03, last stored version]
meshes/link_002.stl
0.0319 x 0.0319 x 0.0185

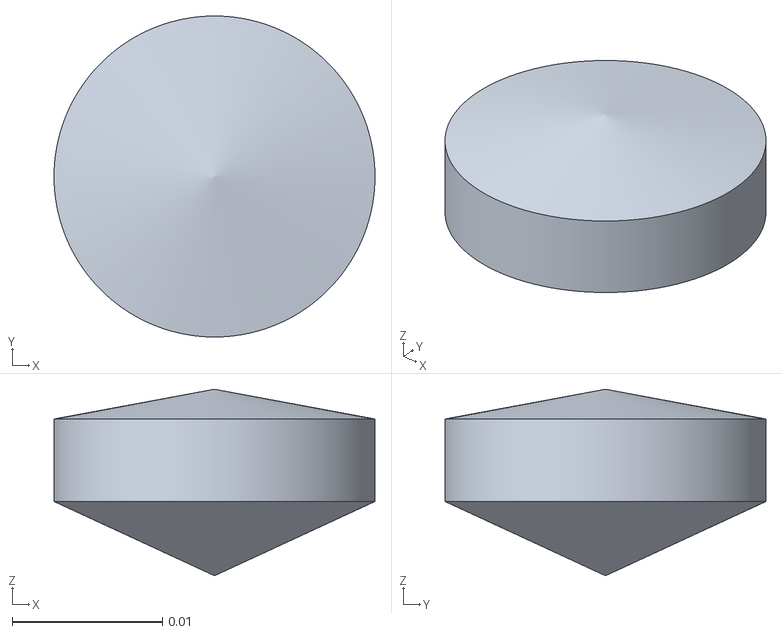
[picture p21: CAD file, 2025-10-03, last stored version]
meshes/link_007.stl
0.0213 x 0.0213 x 0.0124

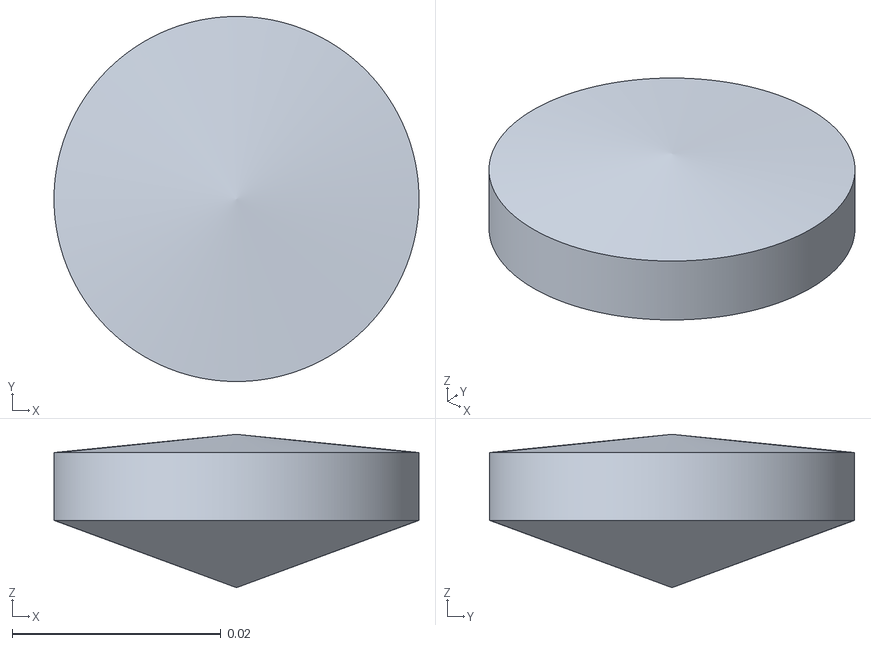
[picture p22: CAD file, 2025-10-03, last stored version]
meshes/link_001.stl
0.0349 x 0.0349 x 0.0147

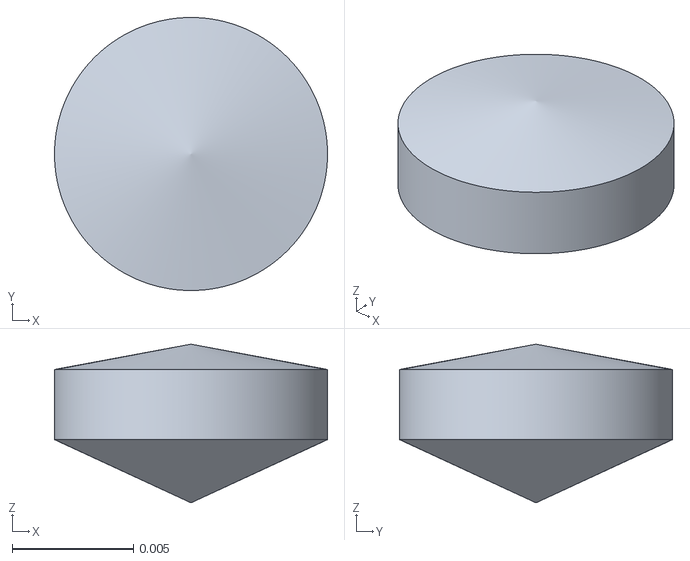
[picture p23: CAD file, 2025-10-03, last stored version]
meshes/link_015.stl
0.0113 x 0.0113 x 0.00654

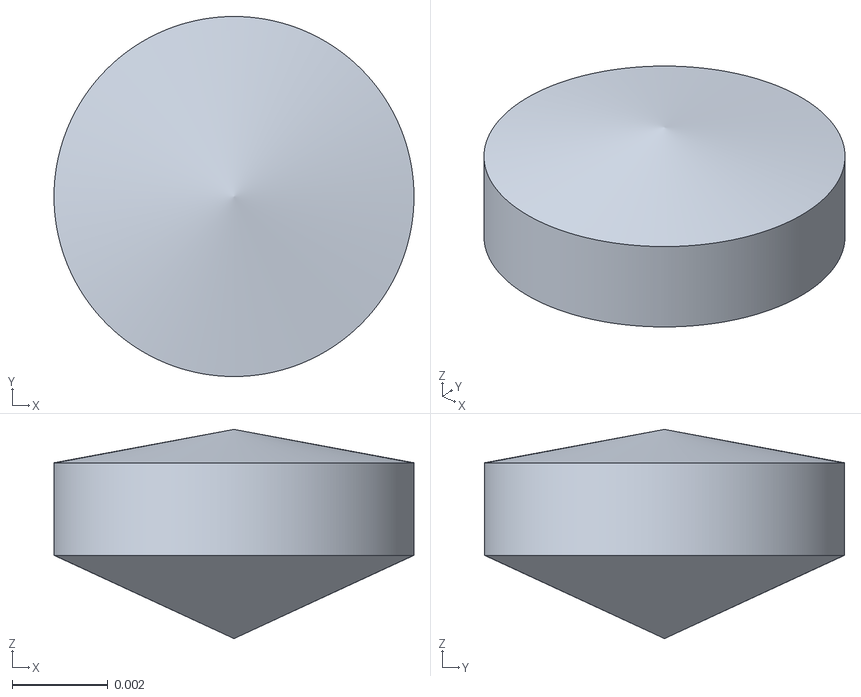
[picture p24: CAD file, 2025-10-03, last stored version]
meshes/link_020.stl
0.00754 x 0.00754 x 0.00438

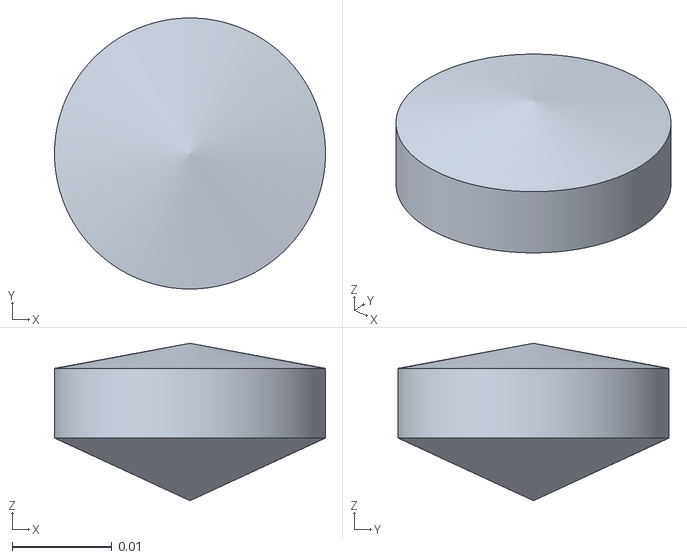
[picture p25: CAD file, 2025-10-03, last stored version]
meshes/link_004.stl
0.0271 x 0.0271 x 0.0158

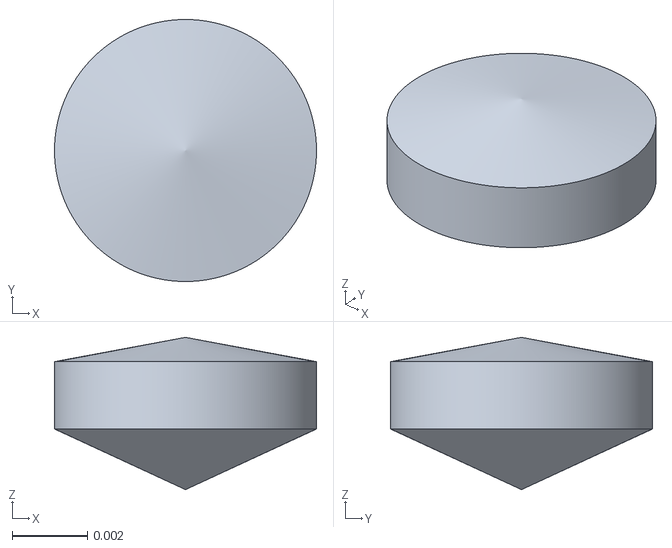
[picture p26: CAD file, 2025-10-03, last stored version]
meshes/link_021.stl
0.00696 x 0.00696 x 0.00404

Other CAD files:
meshes/link_018.stl
meshes/link_017.stl
meshes/link_012.stl
meshes/link_010.stl
meshes/link_003.stl
meshes/link_008.stl
meshes/link_011.stl

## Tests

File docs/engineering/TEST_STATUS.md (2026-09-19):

> Engineering history. For current commands, parameters and supported workflows, use the [main README](../../README.md).

# Understanding the test summary

`passed`, `skipped` and `xfailed` have different meanings. A skipped test was
not run. An expected failure was run and failed a documented expectation.
Neither should be counted as a passing physical validation.

## The 19 skips in the previous delivered suite

| Count | Test group | Reason |
|---:|---|---|
| 16 | `test_collision_workflows.py` face/corner contact probes | The fixture also supplies a three-cable model. These particular assertions require the legacy two-cable box/cylinder compound, so the three-cable cases are intentionally skipped. |
| 3 | `test_convex_collision.py` flat-patch benchmark | The benchmark compares the old constant-thickness rectangular compound against the same rectangular CAD with a hull. The other three section/profile combinations are intentionally excluded from this specific comparison. |

These 19 skips do not indicate missing packages in the validated environment.
Other tests exercise the excluded section/profile combinations. The new
n-cable suite independently tests 3, 4 and 6 cables; it does not rely on the
skipped two-cable compound assertions.

There are also dependency-based skips elsewhere in the project. If your local
count/reasons differ, inspect them: missing CADQuery, MuJoCo or trimesh can
prevent relevant checks. Install the supplied development requirements first.

## The one expected failure: F-08

Test: `tests/test_conventions.py::test_tendon_offset_from_surface_is_constant`.
It is marked `xfail(strict=True)` to track an explicitly deferred routing
decision. The implementation deliberately moves the distal cable site inward:

```text
r1 = max(r_original - inward_shift, 1e-6)
r2 = max(r_original - inward_shift - dz*tan(phi/2), 1e-6)
```

The test expects equal endpoint radii under a constant-offset routing rule;
the existing implementation does not satisfy that expectation. With the
current root parameters, the cable-0 radius reduction within a link ranges
from approximately **0.1601 to 0.6478 mm**. The new two-cable thickness taper
along Y does not eliminate this radial cable-placement rule in the XZ plane.

Despite its name, this test compares the nominal cable-0 endpoint radii. It
does not measure signed clearance from the entire 3D CAD surface. Choosing
the physically correct routing therefore requires comparing the intended
cable guides/holes and actual hardware, not just making this assertion pass.

**Practical assessment:** this is not a newly introduced collision failure
or a build blocker. It is a known modelling discrepancy worth addressing
before quantitative hardware matching, stiffness identification or cable-force
validation, because tendon routing determines cable lengths and moment arms.
It is not evidence that the current routing is physically accurate. It also
does not establish the cause of the earlier arena-memory crashes.

This update preserves existing routing and marks no new expected failures.
Changing it would change dynamics and would need its own validation. The
strict marker causes an unexpected pass to fail the suite until the marker
is deliberately removed, so it cannot quietly become stale after a fix.

## Inspect your own results

```bash
uv pip install -r requirements-dev.txt
uv run python -m pytest -q -rxXs
```

The final lines identify every skip and expected failure. Ordinary failures
remain failures and should be investigated. The validated run's full output
is included in the delivery package under `verification/`.

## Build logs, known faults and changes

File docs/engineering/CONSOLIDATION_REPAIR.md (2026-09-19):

> Engineering history. For current commands, parameters and supported workflows, use the [main README](../../README.md).

# Consolidation repair — 8 September 2026

**Follow-up:** [Link frames and partial base correction](LINK_ORIENTATION_REPAIR.md)
documents the 9 September changes above `5d5b20a`. Byte-identity and CAD-volume
results in this original report describe the preceding repair, not the newly
corrected partial base.

The recovered two-cable CAD had lost the segment gaps and declared metre-sized
coordinates as millimetres. The repair restores the canonical segment outline,
exports at physical size, and checks both solid and mesh topology. It also fixes
build, splitter, array and GUI workflow defects.

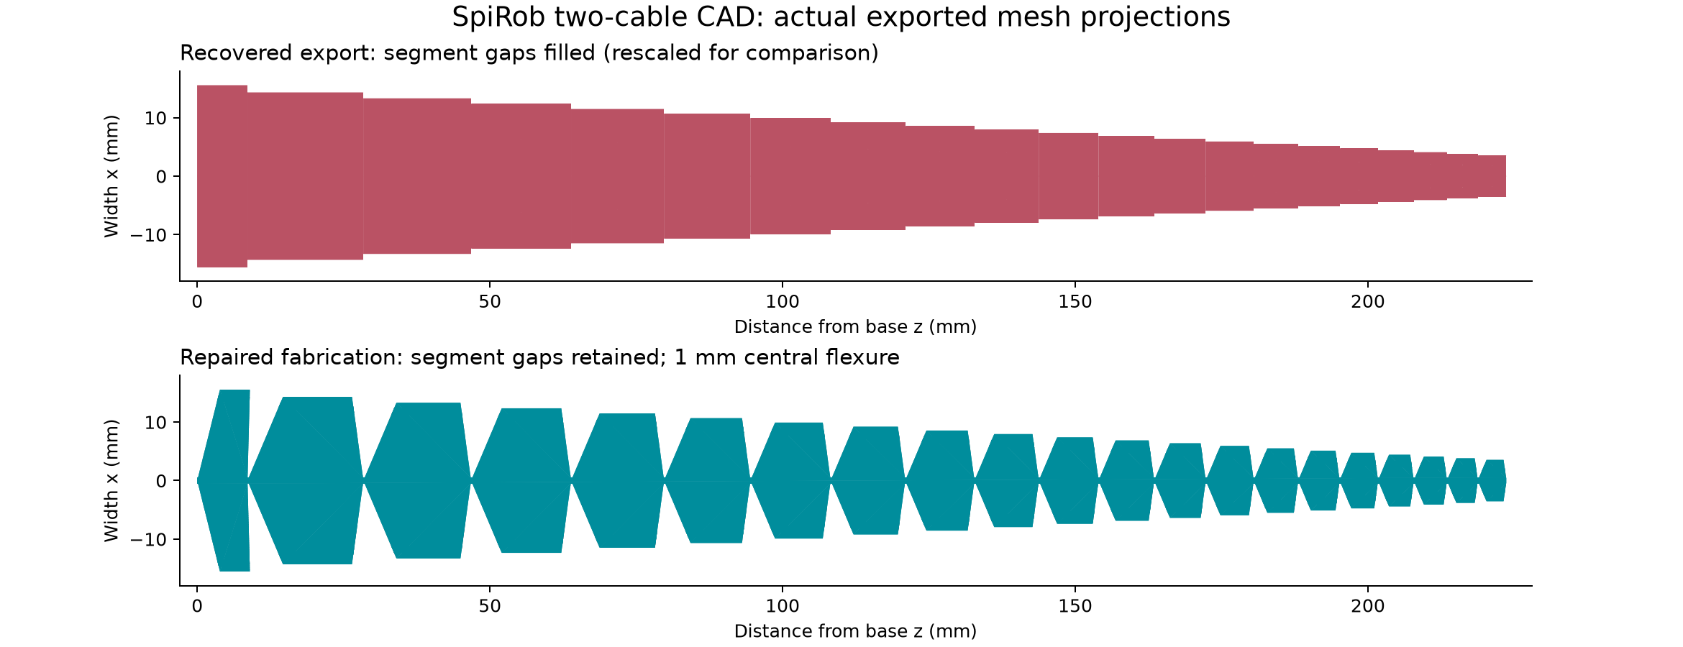
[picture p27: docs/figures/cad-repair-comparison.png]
Actual exported mesh comparison


The old mesh is multiplied by 1000 solely for this shape comparison. Its STEP
header actually declared millimetres. These XZ projections demonstrate segment
gaps, not through-thickness cable-hole geometry or mechanical performance.

## Exact starting points

- Published generator base: `55cc5f10594f9ada18d21b872e4d13fbc266e064`.
- Recovered bundle branch: `consolidate/openspirobs-features`.
- Recovered HEAD: `a980a612c5beb4218b4c09a582520ed0d98b0ed1`.
- Its preceding feature commits: `f389d26` and `0f93648`.
- Recovered bundle SHA-256: `521580f9e4e40b0716826ec4f0b141a790c0a8e6a0ed357e0362ff22a72e24d8`.
- Repair branch: `fix/consolidation-cad-workflows`.
- Downstream mjlab inspected at `ac92b4dda66450edf4cfc23a123c090c53117fe6`.

The Notion page named `0f93648` as final HEAD and a different bundle checksum.
The recovered bundle contains the later lens-section commit `a980a61`. Its
prerequisite and commit objects passed `git bundle verify`; it was imported
without rewriting the inherited commits.

Source handover: [Repo Consolidation](https://app.notion.com/p/3d2b0e637f3a81809732feb02bd0455b).

## Defects and repairs

| Defect reproduced or established in code | Repair |
|---|---|
| Two-cable loft uses joint Z for both centre and edge, filling segment gaps | Preserve all canonical quad vertices; closed piecewise planar lens segments |
| STEP coordinates around 0.224 but header `SI_UNIT(.MILLI.,.METRE.)` | CAD/print geometry explicitly scaled to mm; STEP re-import checks |
| Ideal simulation hinges lack a finite physical ligament | Configurable finite core; fabrication must contain exactly one valid solid |
| No drilled cable channels | Optional swept channels along canonical routed polylines; diameter explicit |
| CAD validity alone does not guarantee watertight exported STL | Remove duplicate/zero-area triangles, weld coincident vertices at 1e-7 mm, validate and re-import STL; no hole-filling repair |
| Shell-string build commands lose path boundaries and interpreter selection | `sys.executable` and argument arrays; paths resolved explicitly |
| Partial/stale mesh folders can be accepted as success | Fresh staging, complete binary STL set validation, MJCF compilation, output rollback on publish failure |
| README advertised `--nlobe` but parser rejected it | Restore compatible alias; cable count still selects section |
| Array leaves sensors/contact/equality references unchanged and loses relative assets | Rename typed references and names, keep world references shared, resolve assets before relocation, compile before write |
| Split box centred at origin on transverse axes | Centre it at the input bounding-box centre; test a solid translated kilometres in numeric CAD space |
| Invalid/duplicate cuts silently ignored; failed fit still reports success | Reject invalid cuts; explicit aggregate fit and failure exit |
| STL splitter misses `networkx` and `rtree` | Explicit optional dependency set |
| GUI touches widgets from workers; save failure does not stop build; CAD uses stale params | Main-thread queue, single active job, validated save gate, CAD rebuild through full pipeline |
| GUI has no splitter controls or exported-mesh inspection | Add both; array count/radius and output path editable |

## Validation performed

Environment: CPython 3.12.13, CadQuery 2.6.1, OCP 7.8.1.1.post1, MuJoCo 3.3.5,
NumPy 2.5.3, pandas 2.2.3, Matplotlib 3.11.1, trimesh 5.1.0. Requirements pin this
validated environment. This is a change from the historical NumPy/CadQuery
installation instructions; cross-version byte identity is not asserted.

- Recovered baseline suite: **185 passed, 1 xfailed**.
- Repaired suite: **198 passed, 1 xfailed** (50.10 s in this environment).
- The prior build-command test inspected a shell string literally. It now checks
  the actual stage arguments, including a parameter path with spaces.
- Separate full builds for 2, 3 and 4 cables all compiled in MuJoCo.
- Two-cable comparison against generator `main`, same interpreter/dependencies:
  geometry CSV + 21 per-link STL files + MJCF XML, **23/23 byte-identical**.
- Six-copy two-cable array, written in a different directory: **127 bodies,
  126 joints, 12 tendons, 12 actuators**. Three/four-cable single models each
  compile as 22 bodies, 21 joints and 3/4 tendons and actuators respectively.
- A separate fixture includes fixed-tendon joint references, sensor object and
  world reference names, equality constraints, contact exclusions and meshdir.
  Its relocated three-copy array compiles with each expected replicated count.
- STEP and STL splitting produce three parts of approximately 74.552 mm along
  Z, fitting a 256 mm cube. The translated-solid and STL-box tests verify volume
  conservation. Drilled two-cable STL splitting also returns closed volumes.
- Failed-build preservation, malformed mesh rejection, non-finite parameters,
  invalid/duplicate cut positions and invalid array counts are covered.

### Two-cable fabrication result

`examples/params-two-cable.json`, centre thickness derived from ratio 0.3,
edge ratio 0.25, core width 1 mm, cable-hole diameter 1 mm:

| Measurement | Result |
|---|---:|
| Width X | 31.087574 mm |
| Thickness Y | 9.326272 mm |
| Length Z | 223.655405 mm |
| CAD volume | 20,304.049177 mm³ |
| Number of CAD solids | 1 |
| STEP valid after re-import | yes |
| STL closed and consistently oriented after re-import | yes |

This is a concrete geometry demonstration, not a prescribed final print design.
`--cable-hole-diameter-mm 0` is the default, so the default solid is undrilled.

## Correct length interpretation

Canonical `LengthReport` gives requested and effective continuous lengths of
226.280000 mm, and discrete chord length of 223.6554047704 mm. Therefore
2.6245952296 mm is the **arc-to-chord deficit**. Unit-completion delta is zero.
The partial unit is `link_001` at the base. The previous handover's explanation
of a missing terminal partial tip unit is incorrect.

The canonical CSV base is at z=2.624595 mm and tip at z=226.280000 mm. Fabrication
translates this frame to put the base at z=0. It does not rescale the chain to
226.28 mm. The simulation's `post_gen` pose remains separate and unchanged.

## Remaining acceptance checks and scope limits

1. **Desktop GUI window unverified.** Tk imports, but opening the window raises
   `TclError: no display name and no $DISPLAY environment variable`. No display
   server is installed. Job-command and parameter-validation tests pass; these
   do not replace opening and exercising the actual desktop window.
2. **Physical performance unverified.** Lens/core dimensions and cable holes need
   printability, wall-thickness, mounting and bend-test review. No physical
   stiffness/damping equivalence, cable clearance qualification, printer trial
   or trained-policy transfer is claimed.
3. **Splitter is geometric.** It supplies no alignment pins, dovetails or bonded
   joint design; build-volume fit does not account for supports or clearances.
4. **Arrays are scoped to generator-style single-robot MJCF.** Assets remain on
   the same filesystem. Includes/keyframes/plugins/structural expansions fail
   explicitly; this is not a generic arbitrary-MJCF cloning library.
5. **MIT provenance boundary.** This repair does not use the authors' source.
   The inherited feature commits' clean-room provenance is their declared
   history and is not independently certified here.

## Repeat the principal checks

```bash
python -m pip install -r requirements-dev.txt
python -m pytest -q
python build.py --params examples/params-two-cable.json --no-preview --output-dir build/two --cad --cable-hole-diameter-mm 1
python build.py --params examples/params-four-cable.json --no-preview --output-dir build/four --cad
python tools/multi_array.py --in build/two/spirob_physics_model.xml --count 6 --out build/array/six.xml
python fabrication/part_splitter.py build/two/cad/spirob.stl --max-span-mm 100 --build-volume-mm 256,256,256
python design_gui.py --params examples/params-two-cable.json --output-dir build/gui
```

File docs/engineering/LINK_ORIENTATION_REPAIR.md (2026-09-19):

> Engineering history. For current commands, parameters and supported workflows, use the [main README](../../README.md).

# Link frames and partial base — 9 September 2026

The base correction below is retained. The frame-viewing workaround described
here is historical: the [10 September Geom-frame update](GEOM_FRAME_ALIGNMENT.md)
adds opt-in alignment of the actual compiled Geom frames.

This follow-up stays on `fix/consolidation-cad-workflows`, above `5d5b20a`.
The user pushed that commit successfully using SSH. This round addresses the
reported link-frame inconsistency and the partial base's reversed-looking cut.

## What the frame display showed

The report was reproduced with MuJoCo 3.3.5. In the two-cable model, the compiled
geom quaternion differs for link 1, links 2–15, link 16 and links 17–21. In the
three-cable model it differs between links 1–14 and links 15–21. All 21 body
frames align at the reference pose in both models.

MuJoCo centres each mesh and aligns it to its principal inertia axes during
compilation, composing the inverse change into the geom placement. Consequently,
the displayed Geom axes can change without rotating the rendered surface.
[MuJoCo 3.3.5 mesh documentation](https://mujoco.readthedocs.io/en/3.3.5/XMLreference.html#asset-mesh)

`tools/inspect_model.py` audits both the body axes and the authored mesh frame,
undoing `mesh_quat`/`mesh_pos` from the compiled geom transform. Its optional
viewer uses **Body** frames and does not advance physics. Joint sliders still
permit inspection of other poses. The GUI's **Inspect link frames** opens it.
Add `--json` to print the full per-link audit.

```bash
python tools/inspect_model.py --mjcf build/two-cable/spirob_physics_model.xml
python tools/inspect_model.py --mjcf build/two-cable/spirob_physics_model.xml --view
```

The native viewer's Geom frames remain MuJoCo's computed frames. No quaternion
compensation is added to rotate real link geometry merely to align those axes.
Use body frames for link transforms; their local +Z points from base toward tip.
Existing `post_gen.robot_pos` / `robot_quat` still place the entire chain.

## Base surface correction

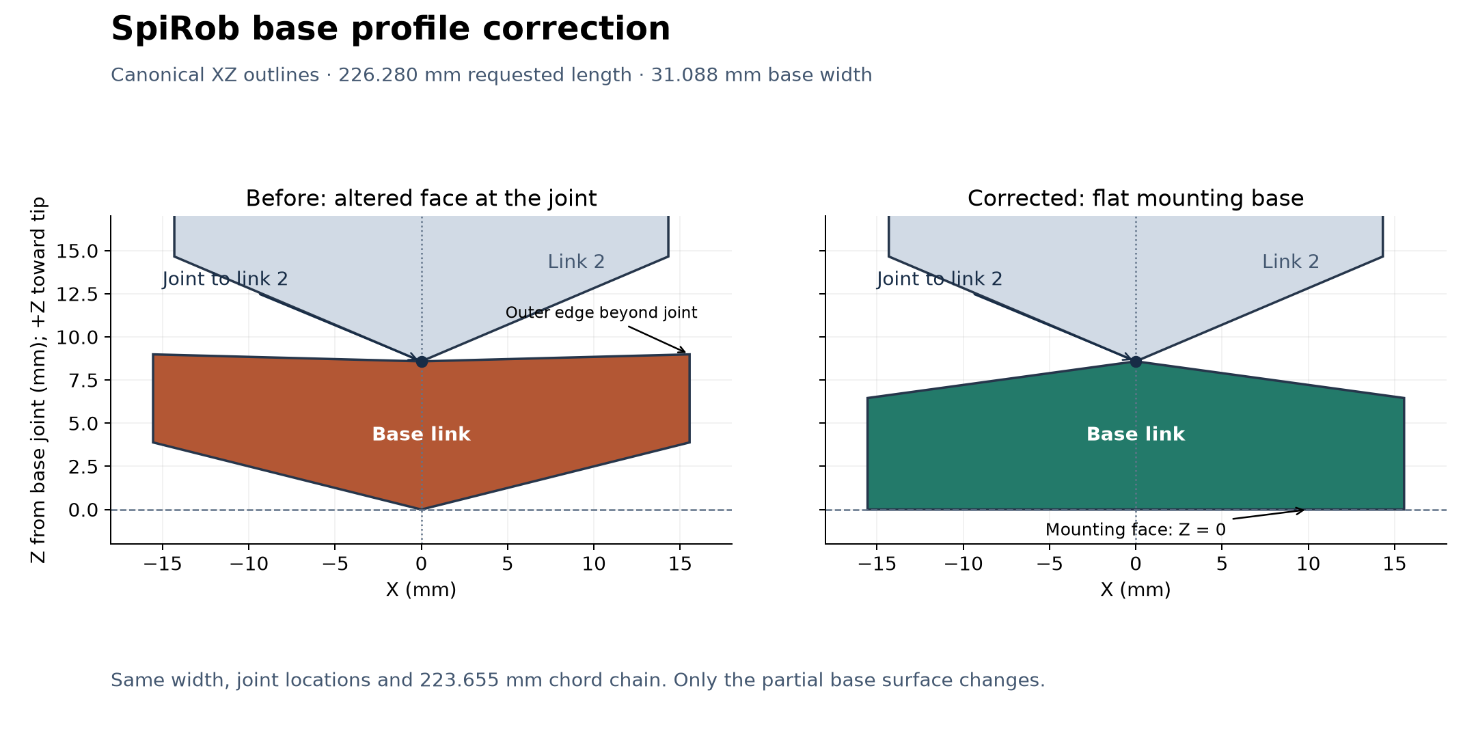
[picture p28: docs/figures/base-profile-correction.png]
Canonical base outline before and after


The shortened last spiral interval correctly becomes the base link. However,
deriving both end-face angles from that shortened interval also changed the
joint-facing face. At the example parameters, the outer corner extended
0.405666 mm beyond the joint to link 2. This made the apparent slice occur at
the joint side.

The canonical model now finishes that partial surface with a flat mounting
plane through the base joint and a joint-facing slope obtained from a complete
canonical unit, scaled to the existing base width. This is a surface correction:
the original radius and both backbone endpoints are retained. It is not a rigid
flip, a change to the requested length, or a claim that the corrected outer
vertices still lie on the unmodified analytical spiral boundary.

The corrected outer vertices are propagated consistently to curled, straight
and inverted poses. The CSV, simulation STL, MJCF cable sites and fabrication
STEP/STL therefore consume the same corrected geometry.

| Local base measurement | Before (mm) | After (mm) |
|---|---:|---:|
| Base joint Z | 0 | 0 |
| Joint to link 2 Z | 8.584200 | 8.584200 |
| Outer base corner Z | 3.887071 | 0 |
| Outer joint-facing corner Z | 8.989866 | 6.460304 |
| Half-width | 15.543787 | 15.543787 |
| Whole chord-chain length | 223.655405 | 223.655405 |

Only a partial base receives this surface finish. `whole_units` retains its
complete-unit geometry. If a requested partial base is too short to retain the
nominal joint face at its current width, generation rejects it with an explicit
message; `whole_units` or a different length/angular span is required.

## Verification and compatibility

- Final suite: **210 passed, 1 existing xfailed** (74.56 s). The expected
  failure remains the previously documented F-08 tendon-routing question.
- Full 2-, 3- and 4-cable builds compile: 22 bodies, 21 joints, and the specified
  number of tendons and actuators.
- All 21 authored mesh frames and body axes align in each reference model.
  The tests reconstruct compiled vertices in their body frames and compare
  against every source STL in both directions, with a 5 nm bound.
- All 20 non-base meshes in the separately generated two-/three-cable models
  are byte-identical to the preceding repair. Body poses, names, joint stiffness
  and damping are unchanged. Non-base body masses are identical.
- The base's mass/inertia and cable coordinates intentionally change with its
  surface. Two-cable simulated base mass changes from 2.380972 to 2.617123 g;
  three-cable base mass changes from 3.814705 to 4.307358 g. These are generated
  MuJoCo masses, not physical measurements or a trained-policy equivalence claim.
- Two-/three-cable fabrication exports with a 1 mm core and 1 mm cable channels
  re-import as one valid CAD solid and a watertight, oriented STL. Two-cable CAD
  remains 31.087574 × 9.326272 × 223.655405 mm; its new volume is 20,400.195734 mm³.
- Regression checks cover the mount plane, nominal joint-face slope, consistent
  poses, several partial lengths, rejection of an inverted surface and detection
  of an actual erroneous mesh transform.

The legacy comparison fixtures now exempt only the intentionally changed base
surface; complete units and all backbone coordinates retain their prior checks.
The two equivalent base STL construction paths differed only by up to
4.34e-19 m at nominally zero coordinates and 5.10e-15 in normals. The base
tessellation comparison uses 1e-12 m tolerance with identical triangle counts;
complete meshes still require identical bytes.

Environment: Python 3.12.14, MuJoCo 3.3.5 and the pinned development requirements.
Desktop interaction still needs workstation acceptance. Regenerate outputs
after applying the commit: old generated files are not rewritten by a Git pull.
The older consolidation report's 23/23 byte-identity and CAD-volume statements
describe `5d5b20a`, before this intentional base correction.

## Rebuild and inspect

```bash
uv pip install -r requirements-dev.txt
python -m pytest -q
python build.py --params examples/params-two-cable.json --no-preview --output-dir build/two-cable --cad --cable-hole-diameter-mm 1
python tools/inspect_model.py --mjcf build/two-cable/spirob_physics_model.xml --view
python build.py --params examples/params-three-cable.json --no-preview --output-dir build/three-cable --cad --cable-hole-diameter-mm 1
python tools/inspect_model.py --mjcf build/three-cable/spirob_physics_model.xml --view
```

Dedicated two-/three-cable examples avoid overwriting your working parameter
file. This review branch remains unmerged.

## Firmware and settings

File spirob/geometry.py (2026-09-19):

"""
Canonical SpiRob geometry model.

=============================================================================
CONVENTIONS OF RECORD
=============================================================================
Every ambiguity that the Phase 1 audit found spread across modules is resolved
here, once. Downstream consumers must not re-derive any of this.

UNITS
    All lengths are metres, all angles are radians, unless a name ends in
    ``_deg`` or ``_mm``. User-facing ``params.json`` keeps its historical
    degree-valued keys (``phi_deg``, ``Delta_theta_deg``); they are converted
    at the boundary in :func:`build_geometry` and never stored in degrees.

PHI
    ``phi`` is the FULL INCLUDED taper angle between the two boundary edges of
    the spiral, not a half-angle. The identity that fixes this is

        d(half-width)/d(arc length) = tan(phi/2)

    so the half-width slope is ``tan(phi/2)``. The parameter is spelled
    ``phi_deg`` in ``params.json`` for backward compatibility; the alias
    ``taper_angle_deg`` is accepted and must agree if both are present.

ANGLE DIRECTION AND REFERENCE AXIS
    ``theta`` increases counter-clockwise from the +X axis. ``theta = 0`` is
    the TIP of the robot (smallest radius); ``theta = q0`` is the BASE
    (largest radius). This is the *curled* frame, centred on the spiral pole.

ORDERING
    Two orderings exist and both are exposed explicitly.

      spiral order   index 0 = theta 0        = smallest = TIP
      link order     index 0 = ``link_001``   = largest  = BASE

    They are exact reverses of one another:  ``link[k] = spiral[N-1-k]``.
    :class:`UnitRecord` carries both ``index_base_to_tip`` (link order, the
    one the CSV/XML use) and ``index_tip_to_base`` (spiral order). Never infer
    ordering from a variable name.

WHAT ``Invert_pose()`` DOES — AND WHY IT IS CORRECT
    ``helper_functions.Invert_pose(quads, Length)`` performs three operations:

      1. reflects y about the requested continuous length:  y -> -y + Length
      2. permutes the vertex slots  [0,1,2,3] -> [1,0,3,2]
      3. reverses the element list

    The result is the intended physical arrangement: LARGEST element at the
    base, SMALLEST at the tip. When the requested length does not contain an
    integer number of nominal units, the partial unit is the last spiral
    interval, and after inversion it becomes ``link_001``, the base link.
    The ordering is preserved. The partial base surface is finished separately:
    its mounting face is flat, and its joint-facing slope matches a complete
    unit. Using the shortened angular interval to derive both faces used to
    put the apparent cut at the joint. Backbone endpoints and widths retain
    their analytical values; only the partial unit's outer vertices change.

    Step (1) anchors the TIP at exactly ``y = requested_length_m``. The base
    therefore sits at ``requested_length_m - discrete_chord_length_m`` in the
    inverted frame. This is a documented frame convention, exposed as
    :attr:`BaseFrame.origin_offset_m`. It does not reach the simulation,
    because ``csv2xml.py`` overrides the root body position from
    ``post_gen.robot_pos``.

LENGTHS — THREE DIFFERENT QUANTITIES
    Do not conflate these. Unit completion and arc-versus-chord shortening are
    separate effects and are reported separately.

      requested_continuous_length_m   what the user asked for
      effective_continuous_length_m   spiral arc actually generated, after the
                                      terminal-unit policy has been applied
      discrete_chord_length_m         sum of straightened chords, i.e. what the
                                      built link chain actually measures

    ``requested -> effective`` is the unit-completion effect (zero under
    ``exact_requested_length``). ``effective -> discrete`` is the arc-to-chord
    shortening effect, always negative, second order in ``Delta_theta``.

WIDTHS
    ``nominal`` widths come from ``d(theta) = a*(E-1)*exp(b*theta)``.
    ``realized`` widths are what straightening actually produces:

        realized_width = d(theta_start) * dist(O, chord) / r_c(theta_start)

    The sagitta factor is < 1, so realized < nominal. Both are reported.

TENDON POINTS
    Defined once, here, in the inverted (CSV) frame. Two stages:

      attachment points   the raw inner-edge vertices, radius = local surface
      routing points      after ``tendon_inward_shift`` and the per-link
                          ``-dz*tan(phi/2)`` correction

    The routing stage reproduces ``csv2xml.py`` exactly (verified to 1e-15 by
    ``tests/test_canonical_geometry.py``) so that adopting this model changes
    no routing convention. The partial base surface correction intentionally
    changes that link's attachment/routing points. See ``docs/engineering/GEOMETRY_AUDIT.md`` F-08 for the open
    question about whether that correction is the right long-term rule.

FABRICATION ANCHORS (deferred to a later phase)
    :class:`BaseFrame` and :attr:`UnitRecord.slit_reference_m` expose stable
    named locations for a future CAD exporter (base dovetail, inter-unit
    slits). No solids are built here.
"""

from __future__ import annotations

import math
from dataclasses import dataclass, field, replace
from enum import Enum
from typing import Dict, List, Optional, Sequence, Tuple

import numpy as np

__all__ = [
    "TerminalUnitPolicy", "UserInputs", "SpiralParameters", "LengthReport",
    "UnitRecord", "TendonPoint", "TendonPath", "BaseFrame", "Tolerances",
    "SpiRobGeometry", "build_geometry",
]


# ══════════════════════════════════════════════════════════════════════════
#  Tolerances
# ══════════════════════════════════════════════════════════════════════════

@dataclass(frozen=True)
class Tolerances:
    """Numerical tolerances, all documented and all overridable.

    angle_rad
        Two angles closer than this are considered equal. Used to decide
        whether ``q0/Delta_theta`` is an exact integer, i.e. whether a partial
        unit exists at all. 1e-9 rad is ~2e-4 arc-seconds.
    length_m
        Two lengths closer than this are equal. 1e-12 m is well below any
        printable or simulable feature at this scale.
    solver_rel
        Relative convergence target for iterative solvers.
    solver_max_iter
        Hard iteration cap; exceeding it raises rather than returning a
        half-converged root.
    """
    angle_rad: float = 1e-9
    length_m: float = 1e-12
    solver_rel: float = 1e-12
    solver_max_iter: int = 200


# ══════════════════════════════════════════════════════════════════════════
#  Policy
# ══════════════════════════════════════════════════════════════════════════
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

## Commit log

2025-10-03 Initial commit: Spirob pipeline (CSV → STL → XML)
    [Spirob_geom_data.csv, link_001.stl, link_002.stl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]
2025-10-03 Remove generated outputs (meshes, CSV, XML) from repo and add to .gitignore
    [Spirob_geom_data.csv, link_001.stl, link_002.stl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]
2025-10-03 Update csv2xml.py
    Fix tendon site logic in csv2xml.py where earlier it was just selecting s1 site of the element. Now it selects s1 and s2 both.
2025-10-25 Update csv2xml.py
    added class = "cable_motor" in both actuator and the default tag under default tag.
2025-11-21 Update build.py
    added comment on line 42 # change csv2geom.py to csv2geom_trilob.py for trilob geometry (3 cable model)
2025-11-21 Update csv2xml.py
    Tendon routing made closer to the body. Now tendon moves through the body and is not rendered outside the body.
2026-03-06 added .docx file of README and csv2geom_nlobe.py
    single STL generator
2026-03-06 Update helper_functions.py
    Minor corrections that prevents plt.show from blocking the flow.
2026-03-07 preview.py added
    before building the xml and stl, a script to do visual geom check by user
2026-05-01 add touch sensor for each link
2026-05-08 Update add_touch_sensor.py
    Adds touch sensor of adaptive size (sphere) along the tendon location (middle) + some offset given by OFFSET_MARGIN. Also allows you to select the link number on which to add the sensors.
2026-05-08 Create 2_cable_touch_debug.py
    Just a touch debug tool for 2 cable spirob. Doesn't work for > 2 cables spirob.
2026-05-12 Update 2_cable_touch_debug.py
    fixed the ctrl + up/down not working and removed the ctrl + l logic as mujoco's viewer it self has reset button which does the same work and can be accessed via keyboard button Backslash.
2026-05-13 Update 2_cable_touch_debug.py
    Updated the sim step rate =/= wall clock rate =/= control input rate causing sluggish movement of the 2 cable spirob.
2026-05-13 Update 2_cable_touch_debug.py
    Added check for two actuators and two tendons as this debug script is applicable only for 2 cable SpiRob.
2026-05-13 Update add_touch_sensor.py
    Adds sensor in xml in formatted way with proper indentation. previously it was just adding them in the same line.
2026-07-22 audit: Phase 1 geometry audit, read-only manifest tool, analytical + convention tests
    Adds docs/GEOMETRY_AUDIT.md, tools/geometry_audit.py and tests/.
    No production code path is modified.
    Verified against the committed defaults to 10 s.f.:
    b=0.1369640839 a=0.0052319156 q0=10.9632013369
    d_root=0.0320448838 beta=1.076353346
    continuous arc 226.2800 mm vs discrete backbone 223.6554 mm
    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
2026-07-22 feat(geometry): canonical geometry layer with explicit terminal-unit policy
    Introduces spirob/geometry.py as the one authoritative geometric description
    of a SpiRob, computed once and consumed downstream. Depends only on the stdlib
    and NumPy — no matplotlib, MuJoCo, CadQuery, Qt or VTK.
    Default output is byte-identical to 40fb850: CSV, MJCF XML and all 21 STL
    files compare equal.
    Terminal-unit policy
    exact_requested_length (default) preserves the requested continuous length
    and permits one partial unit at the base
    whole_units extends the spiral to the next complete unit
    boundary, never shortens, reports the excess
    Fo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
    [geometry.py]
2026-07-23 docs: reconcile geometry audit with canonical findings
    Documentation-only. No production code, tests, or generated CSV/XML/STL
    artefacts are touched. Historical Phase 1 conclusions are struck through and
    annotated rather than deleted, so the original reasoning stays auditable.
    Invert_pose() is correct
    The partial unit belongs at the base after inversion. It is partial in
    angular span while remaining at the large-radius, wide end; the smallest
    element remains at the tip. Removed the residual "truncation"/defect framing
    that implied an inversion or ordering error.
    F-04 is not a base-position defect
    The inversion intentionally anchors the tip at the requested length, and
    csv2xml.p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
2026-07-24 refactor(csv): consume canonical geometry model
    spirob_csv_generator.py no longer derives the spiral. b, a, q0, the spiral
    pose, the straightened pose and the inverted pose now come from
    spirob/geometry.py via from_params(); the module retains only params.json
    validation and CSV serialisation.
    Removed duplication
    solve_b_for_phi / e2pb / a / A / q0 recomputation
    generate_spiral_pose -> straighten_pose -> Invert_pose chain
    the "from helper_functions import *" star import
    Retained shim
    helper_functions.generate_cable_sites_csv_zrot_from_P remains the CSV
    writer. Serialisation is not geometry, and keeping it is what guarantees
    identical column layout and float formatting.
    Numeric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
    [geometry.py]
2026-07-27 refactor(stl): consume canonical geometry model
2026-09-05 feat: consolidate OpenSpiRobs fabrication/CAD features (clean-room, MIT)
    Add four capabilities inspired by the OpenSpiRobs toolkit (Zhanchi Wang et al.,
    PolyForm-Noncommercial), reimplemented clean-room on this repo's own MIT geometry
    stack — no upstream code copied — and supporting the full n-cable range:
    - cad_export.py: whole-robot STEP + solid STL export (assembles per-element
    solids in world coordinates). Wired into build.py via --cad / --fuse-cad.
    - fabrication/part_splitter.py: build-volume-aware splitter for STEP (CadQuery)
    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
2026-09-08 fix(cad): export 2-cable model as a uniform-thickness flat leaf plate
    Match the shape the original OpenSpiRobs design tool exports for the flat
    (2-cable) case: an unfolded tapered outline extruded to a single CONSTANT
    thickness, instead of the previous per-element tapered thickness.
    - cad_export.py: flat elements now build a full-width symmetric trapezoid
    (mirrored across the central axis) extruded to one constant thickness,
    computed once as flat_thickness_ratio × base outer diameter (override with
    --flat-thickness-m). Clean-room, on this repo's own quad data.
    - README: document 2-cable flat-plate behaviour + --flat-thickness-m.
    Verified: constant 9.33 mm thickness across all 21 ele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
2026-09-08 feat(cad): 2-cable lens cross-section (thick centre → thin cable-hole edges)
    Replace the flat 2-cable plate with a lens (biconvex) cross-section: thickness
    is highest at the centre-line and tapers toward both lateral edges (where the
    cables/holes sit), matching the physical SpiRob. Each element is lofted from its
    base to tip section so the width tapers while the lens is preserved.
    - cad_export.py: _flat_element_world now lofts a hexagonal lens section;
    centre thickness = flat_thickness_ratio × base outer diameter (--flat-thickness-m),
    edge thickness = flat_edge_ratio × centre (default 0.25, --flat-edge-ratio).
    - README: document the lens section + flags.
    Verified: centre 9.33 mm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
2026-09-09 fix: correct partial base face and clarify link frame inspection
    [geometry.py]
2026-09-10 fix: align compiled SpiRob geom frames with compensated mesh coordinates
2026-09-16 feat: add inertia audit and protected-base joint tuning tools
2026-09-17 feat: add opt-in six-sided two-cable section and inspection tool
2026-09-18 Taper two-cable link thickness continuously along the robot
2026-09-18 Reduce two-cable contacts with one massless convex collider per link
2026-09-19 Support n-cable convex colliders and hide the target marker by default
2026-10-04 Support constant two-cable thickness in designer and all exports
2026-10-05 Cut straight validated cable bores and preview hole openings
2026-10-12 Align joint gains with explicit joint-2 experimental convention
